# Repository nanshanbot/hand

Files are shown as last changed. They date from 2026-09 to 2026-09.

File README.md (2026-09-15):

# 11 自由度仿生机械手

这是一个基于 STM32F103、PCA9685 和 MediaPipe 的 11 自由度右手机械手项目。项目包含机械结构文件、嵌入式控制固件、串口调试工具，以及普通摄像头手势控制和 RGB-D 连续动作跟随程序。

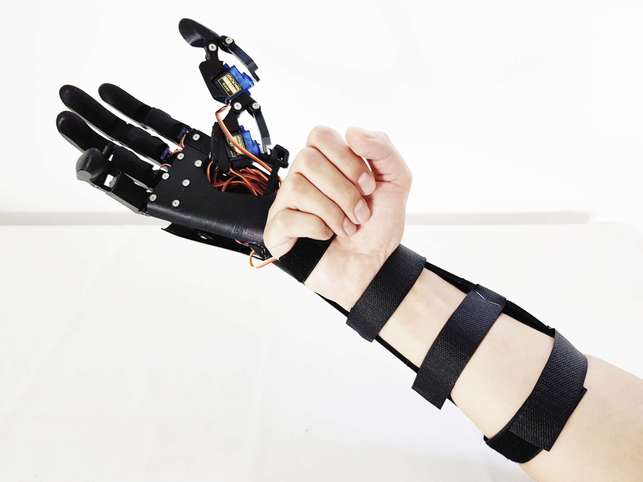
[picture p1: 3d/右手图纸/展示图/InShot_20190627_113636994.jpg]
机械手实物展示


## 功能

- 通过 PCA9685 驱动 11 路舵机
- 通过 USB 转串口独立调试每个关节
- 使用 MediaPipe 识别 8 种常用手势并映射为机械手姿态
- 使用 Orbbec Gemini 336 深度相机估算真实 3D 关节角
- 对识别结果进行稳定帧判断、滤波和舵机速度限制
- 保存和载入 JSON 格式的机械手姿态
- 提供 STL、SolidWorks 源文件、结构图和组装手册

## 项目结构

```text
robot_hand/
├─ 3d/右手图纸/                 # STL、SolidWorks、结构图和组装手册
├─ code/hand/                   # STM32F103 固件
│  ├─ Core/                     # 应用代码与外设初始化
│  ├─ Drivers/                  # STM32 HAL 与 CMSIS
│  └─ tools/hand_debugger/      # Python 串口调试台
└─ code/py/
   ├─ shoushi.py                # 普通摄像头手势识别控制
   ├─ main.py                   # RGB-D 关节角连续跟随
   ├─ gesture_recognizer.task   # MediaPipe 手势识别模型
   └─ hand_landmarker.task      # MediaPipe 手部关键点模型
```

## 硬件

- STM32F103 控制板
- PCA9685 16 路 PWM 驱动板，默认 I2C 地址 `0x40`
- 11 个舵机及机械手结构件
- 3.3 V TTL USB 转串口模块
- 独立舵机电源
- 普通 USB 摄像头，或 Orbbec Gemini 336 RGB-D 相机

> 舵机电源不要直接取自 STM32。舵机电源、STM32 和 PCA9685 必须共地，首次调试建议先卸载拉线或断开舵机负载，确认角度方向和限位正确后再组装。

### USB 转串口接线

| STM32F103 | USB 转串口 |
| --- | --- |
| PA9 / USART1_TX | RX |
| PA10 / USART1_RX | TX |
| GND | GND |

串口参数固定为 `115200, 8N1`。

## 固件编译与烧录

固件工程位于 `code/hand`，由 STM32CubeMX 生成基础工程，并使用 CMake 构建。需要提前安装 ARM GNU Toolchain、CMake 和 Ninja。

```powershell
cd code\hand
cmake --preset Debug
cmake --build --preset Debug
```

生成的固件位于 `code/hand/build/Debug/hand.elf`。可使用 STM32CubeProgrammer、ST-Link 或支持 ELF 文件的调试器烧录。修改 CubeMX 配置时请使用 `code/hand/hand.ioc`。

## 串口调试台

Windows 下可直接双击：

```text
code\hand\tools\hand_debugger\run.cmd
```

也可以在 PowerShell 中运行：

```powershell
cd code\hand
.\tools\hand_debugger\run.ps1
```

脚本首次启动会在工具目录创建虚拟环境并安装 `pyserial`。连接串口后，可以分别调整 11 路关节角、实时下发命令、预览姿态，以及保存或载入姿态文件。

通道定义如下：

| 通道 | 关节 | 角度范围 |
| --- | --- | --- |
| CH0 | 拇指旋转 | 5-140° |
| CH1 | 拇指近端 | 5-170° |
| CH2 | 拇指远端 | 5-140° |
| CH3-CH4 | 食指近端、远端 | 5-170° |
| CH5-CH6 | 中指近端、远端 | 5-170° |
| CH7-CH8 | 无名指近端、远端 | 5-170° |
| CH9-CH10 | 小指近端、远端 | 5-170° |

## 视觉控制

建议使用 Python 3.10 创建独立环境：

```powershell
cd code\py
py -3.10 -m venv .venv
.\.venv\Scripts\Activate.ps1
python -m pip install -r requirements.txt
```

RGB-D 模式还需要按 [Orbbec SDK 文档](https://github.com/orbbec/pyorbbecsdk) 安装与设备、系统匹配的 `pyorbbecsdk`。

### 普通摄像头手势控制

`shoushi.py` 使用 MediaPipe 内置手势分类器，将 `Closed_Fist`、`Open_Palm`、`Victory` 等手势映射为预设的 11 路舵机角度。

```powershell
python shoushi.py --port COM20 --camera 0
```

使用其他串口或摄像头时修改对应参数。运行中按空格键暂停或恢复控制，按 `Q` 退出。执行下面的命令可以进入姿态标定模式：

```powershell
python shoushi.py --calibrate --camera 0
```

### RGB-D 连续动作跟随

`main.py` 面向 Orbbec Gemini 336。程序使用彩色图像检测 21 个手部关键点，再利用对齐的深度图反投影到相机坐标系，经过骨长约束和平滑处理后映射到舵机角度。

```powershell
python main.py --port COM20 --debug
```

关节范围标定：

```powershell
python main.py --calibrate
```

标定窗口中，右手完全伸直时按 `1`，完全握拳时按 `2`，各采集多组数据后按 `3` 输出新的 `MP_RANGES`。

> 当前仓库缺少 `code/py/rgbd_hand_3d.py` 源文件，`main.py` 在补回该模块前无法从全新环境运行。该模块应提供 Gemini 336 采集、深度反投影、骨长约束和关键点平滑功能；请不要用 `__pycache__` 中的 `.pyc` 文件代替源码上传。

## 串口协议

每条 ASCII 命令以回车或换行结束：

```text
PING          -> PONG
GET           -> STATE 5,5,5,5,5,5,5,5,5,5,5
SET 0 90      -> OK
ALL 5         -> OK
```

- `SET <通道> <角度>` 设置单路舵机。
- `ALL <角度>` 设置全部舵机；CH0 和 CH2 最高会限制在 140°。
- 参数或通信异常时，控制板返回以 `ERR` 开头的错误信息。

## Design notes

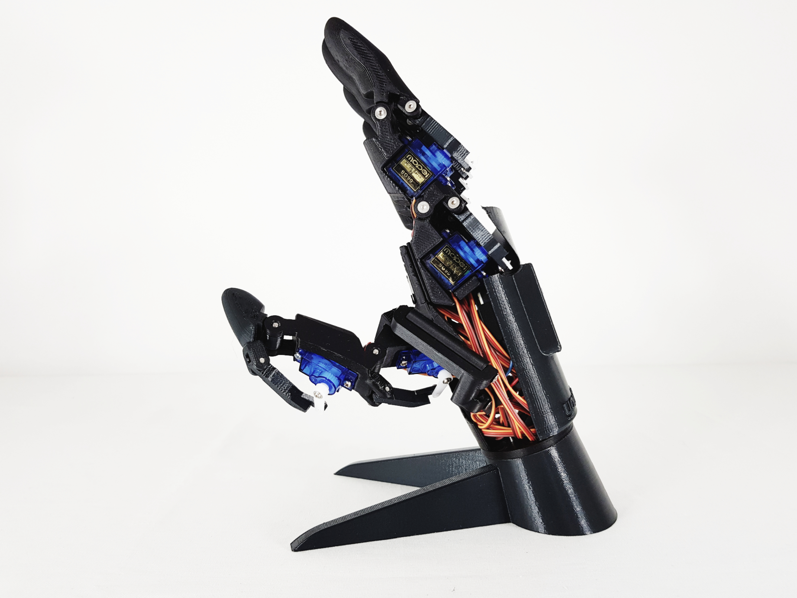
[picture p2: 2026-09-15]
3d/右手图纸/展示图/InShot_20190323_112702161.jpg

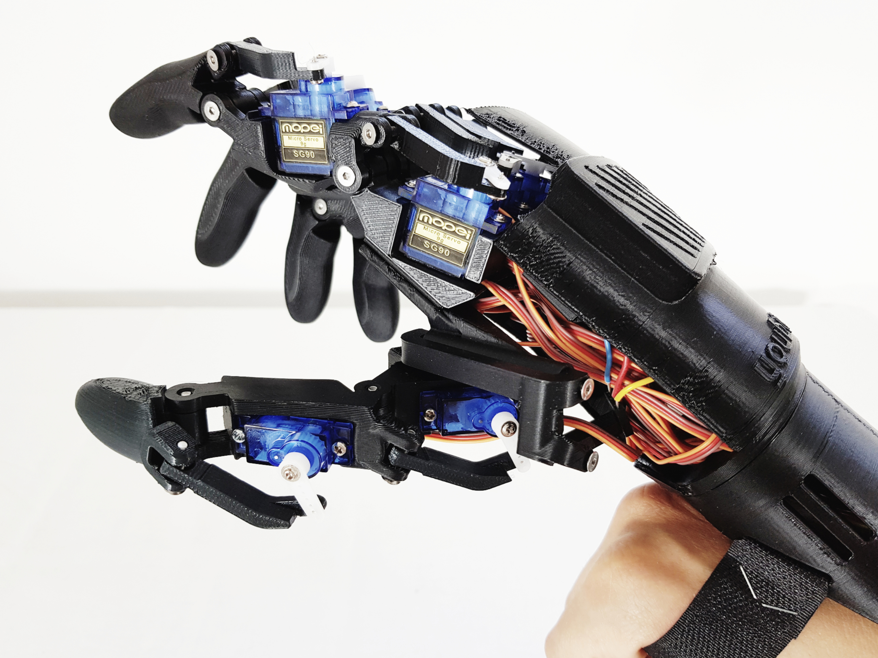
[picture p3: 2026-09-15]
3d/右手图纸/展示图/InShot_20190627_113036899.jpg

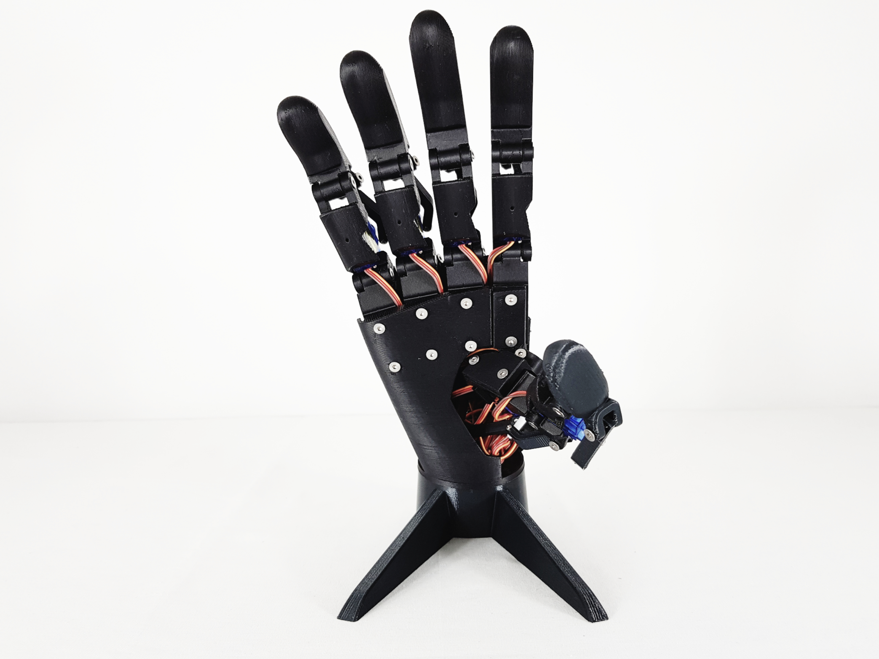
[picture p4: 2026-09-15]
3d/右手图纸/展示图/InShot_20190323_112803288.jpg

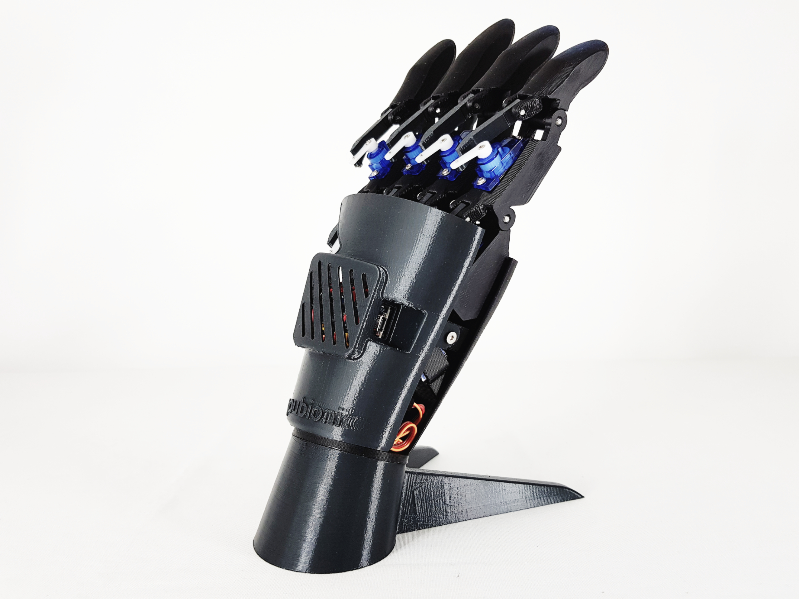
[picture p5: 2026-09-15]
3d/右手图纸/展示图/InShot_20190323_112944940.jpg

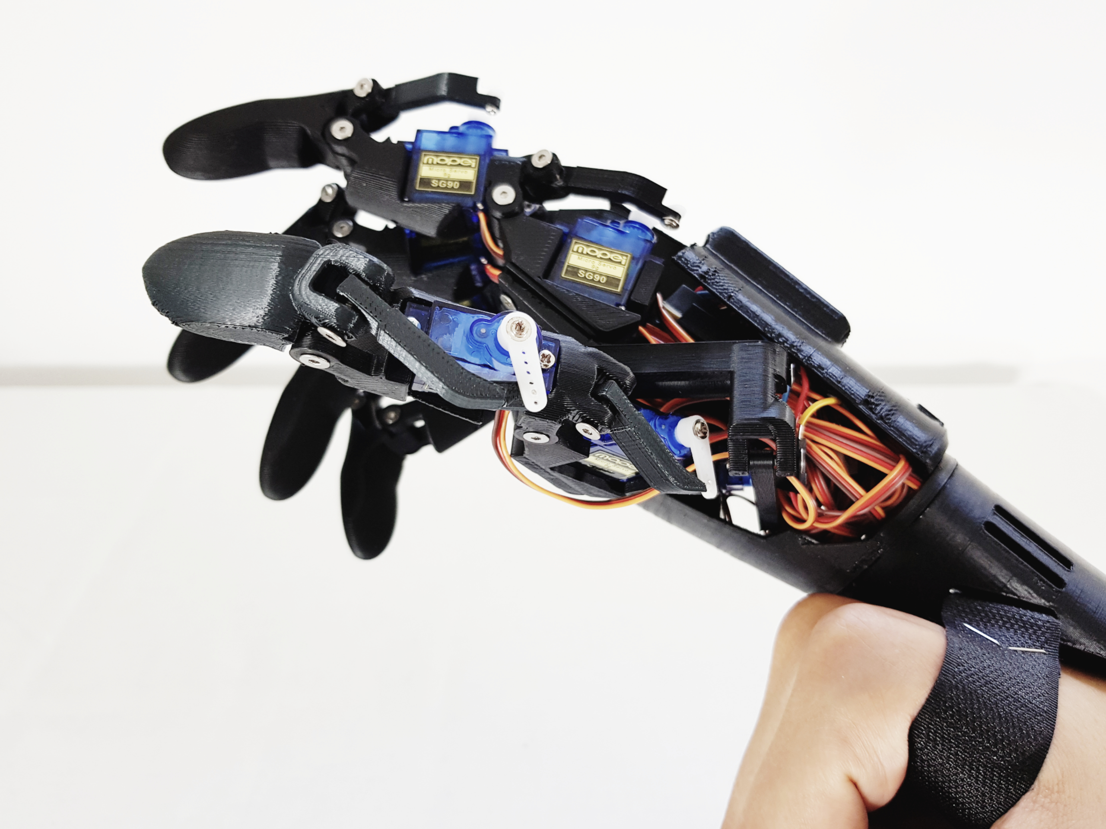
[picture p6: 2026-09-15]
3d/右手图纸/展示图/InShot_20190627_113151180.jpg

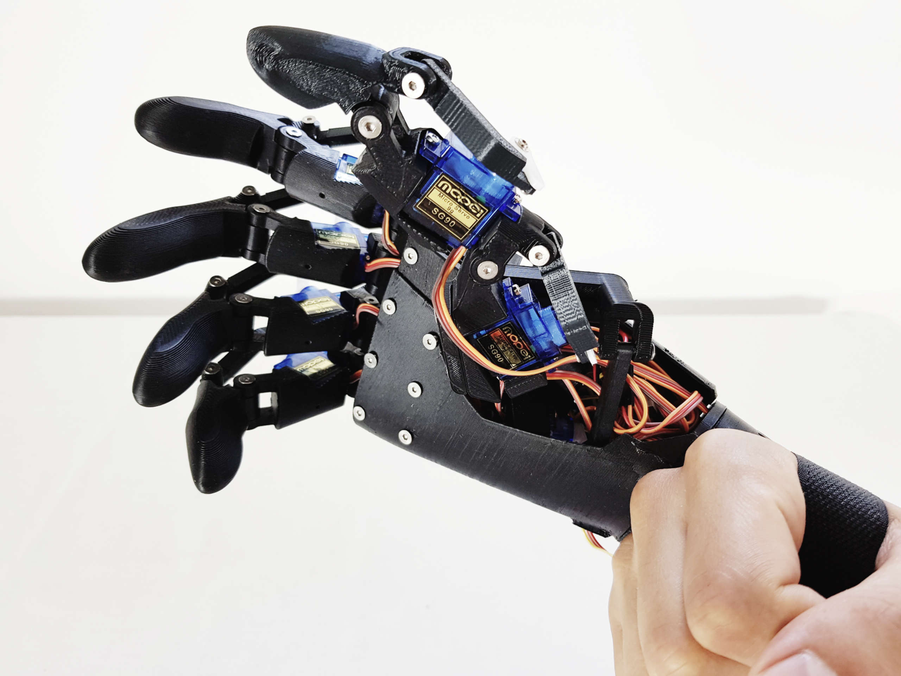
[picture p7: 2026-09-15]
3d/右手图纸/展示图/InShot_20190627_113228893.jpg

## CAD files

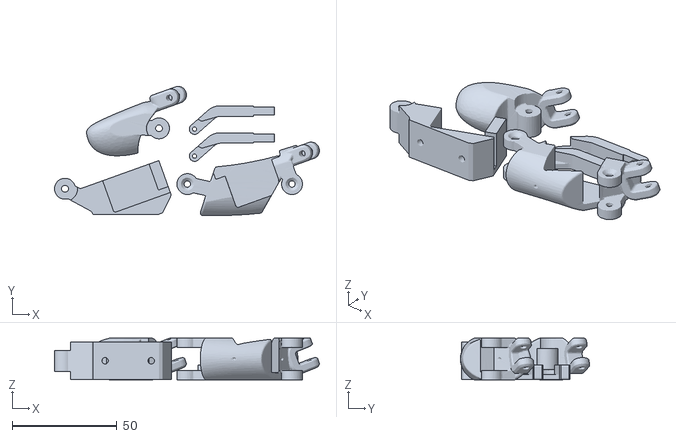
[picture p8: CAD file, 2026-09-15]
3d/右手图纸/stl/Handy_Thumb.stl
126.6 x 61.8 x 20.0

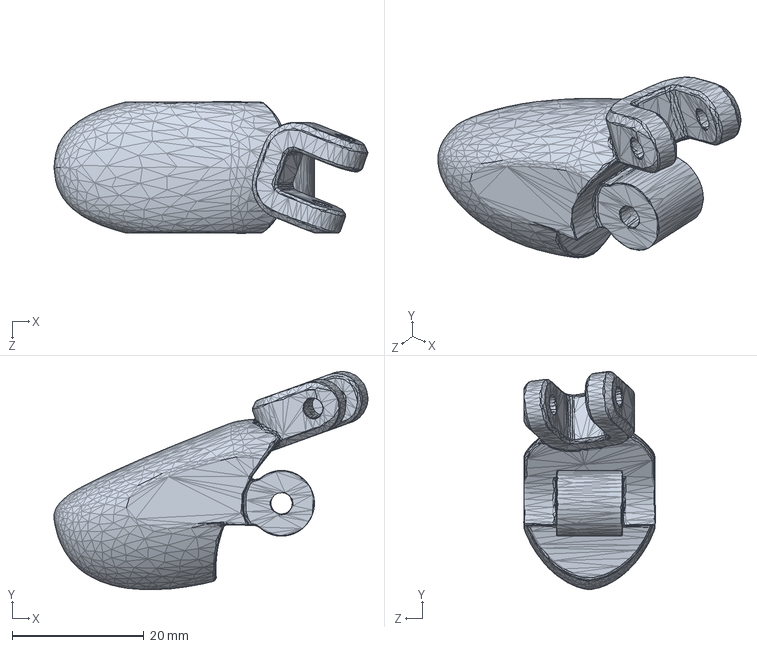
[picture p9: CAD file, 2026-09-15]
3d/右手图纸/sw/Handy_Thumb.SLDPRT
47.8 x 33.2 x 20.0 mm

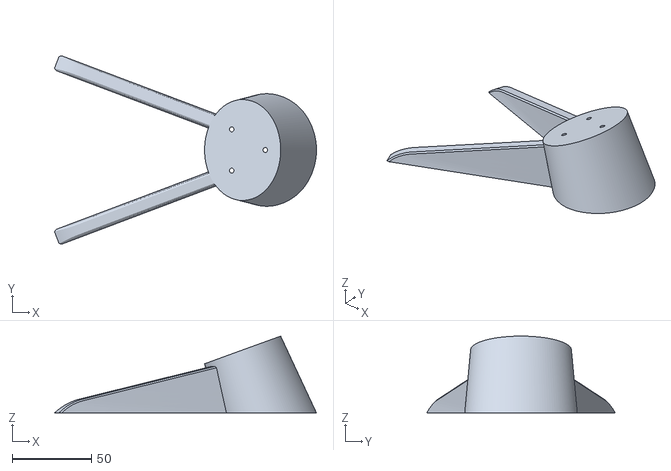
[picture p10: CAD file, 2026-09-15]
3d/右手图纸/stl/Handy_Dock Station.stl
165.0 x 118.6 x 48.4

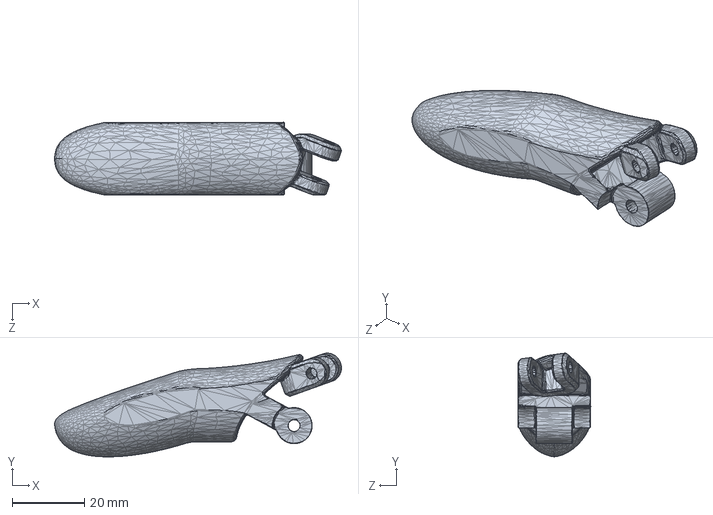
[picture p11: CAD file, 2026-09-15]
3d/右手图纸/sw/Handy_Middle.SLDPRT
79.4 x 28.7 x 20.2 mm

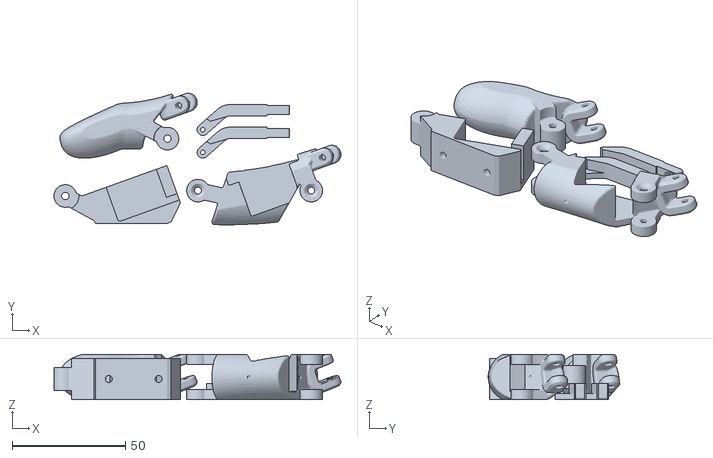
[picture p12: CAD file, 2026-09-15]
3d/右手图纸/stl/Handy_Pinkie.stl
126.7 x 58.1 x 20.0

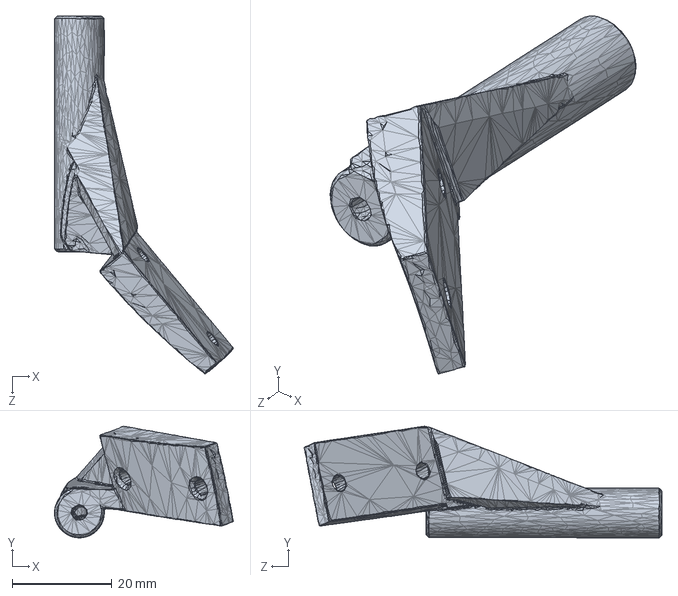
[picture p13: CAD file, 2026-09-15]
3d/右手图纸/sw/Handy_Palm and Rotation - Right update2.SLDPRT
35.9 x 22.4 x 71.8 mm

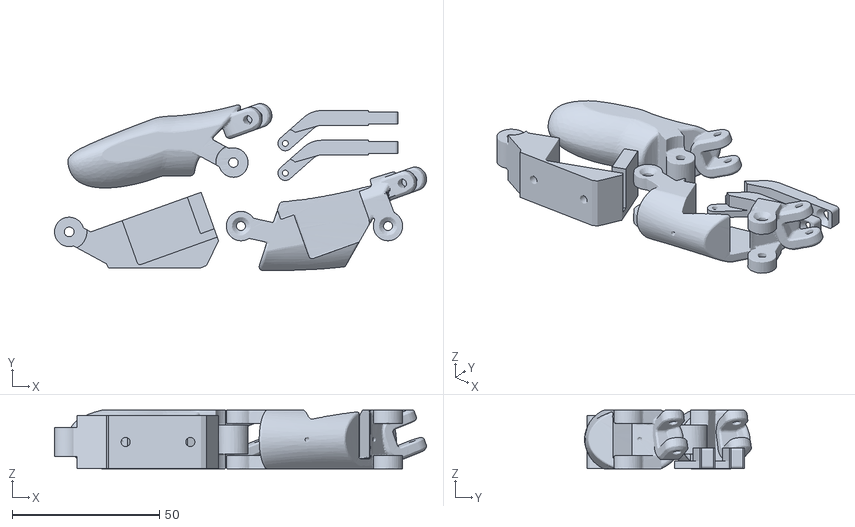
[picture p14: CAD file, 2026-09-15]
3d/右手图纸/stl/Handy_Index.stl
126.5 x 56.7 x 20.0

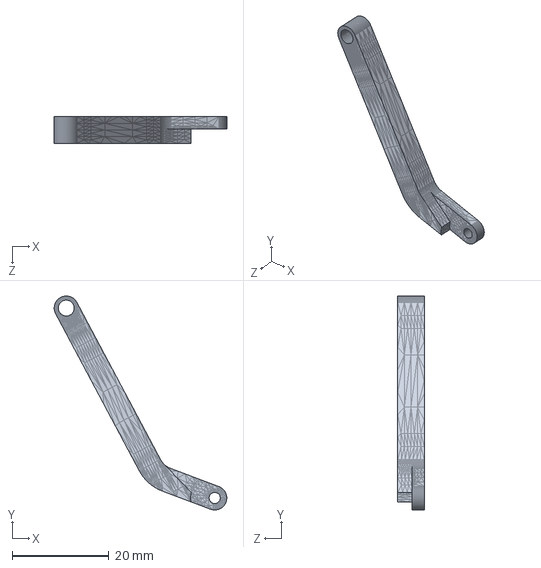
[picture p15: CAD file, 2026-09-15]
3d/右手图纸/sw/Handy_Palm and Rotation - Right update3.SLDPRT
35.8 x 44.3 x 5.50 mm

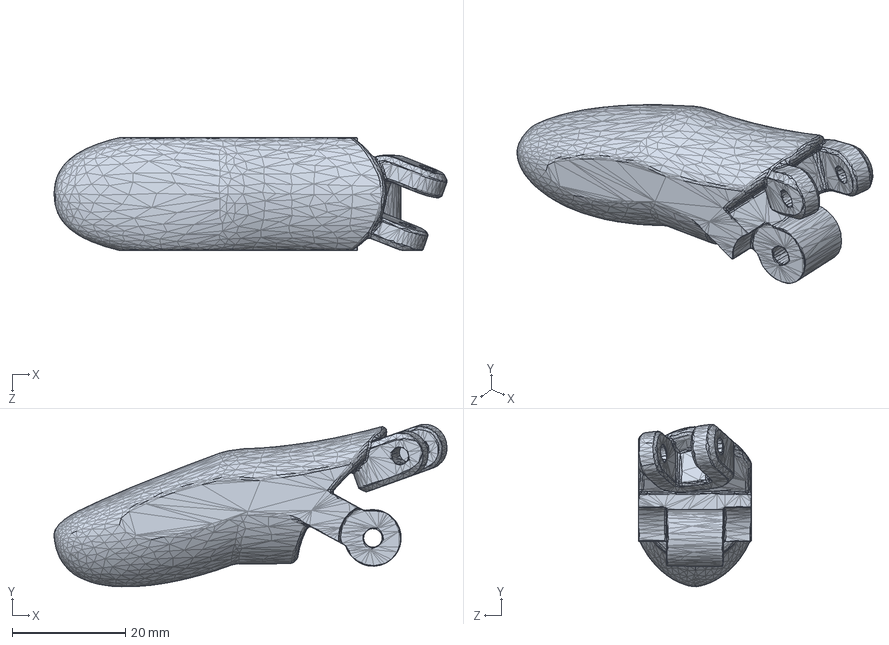
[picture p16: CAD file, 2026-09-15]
3d/右手图纸/sw/Handy_Index.SLDPRT
69.4 x 28.7 x 20.0 mm

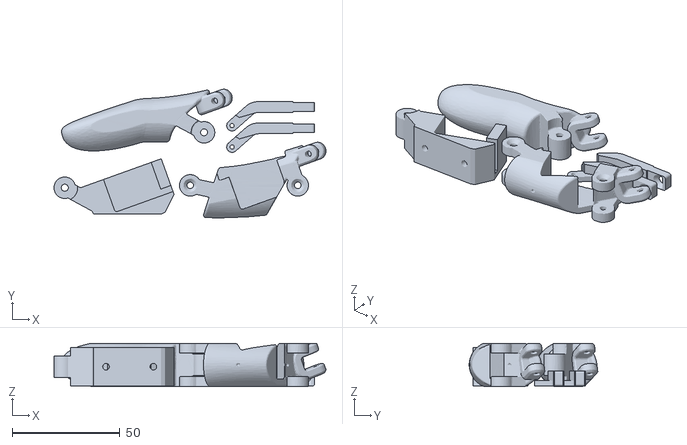
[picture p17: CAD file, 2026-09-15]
3d/右手图纸/stl/Handy_Middle.stl
126.4 x 59.8 x 20.2

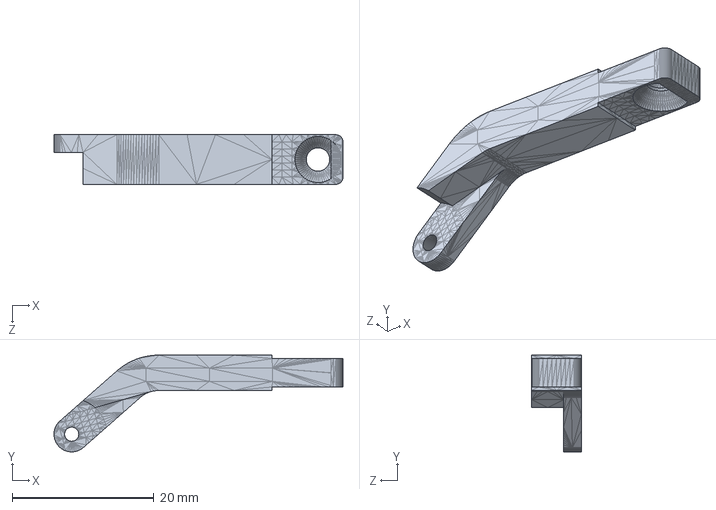
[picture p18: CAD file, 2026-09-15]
3d/右手图纸/sw/Handy_Middle3.SLDPRT
40.8 x 13.7 x 7.00 mm

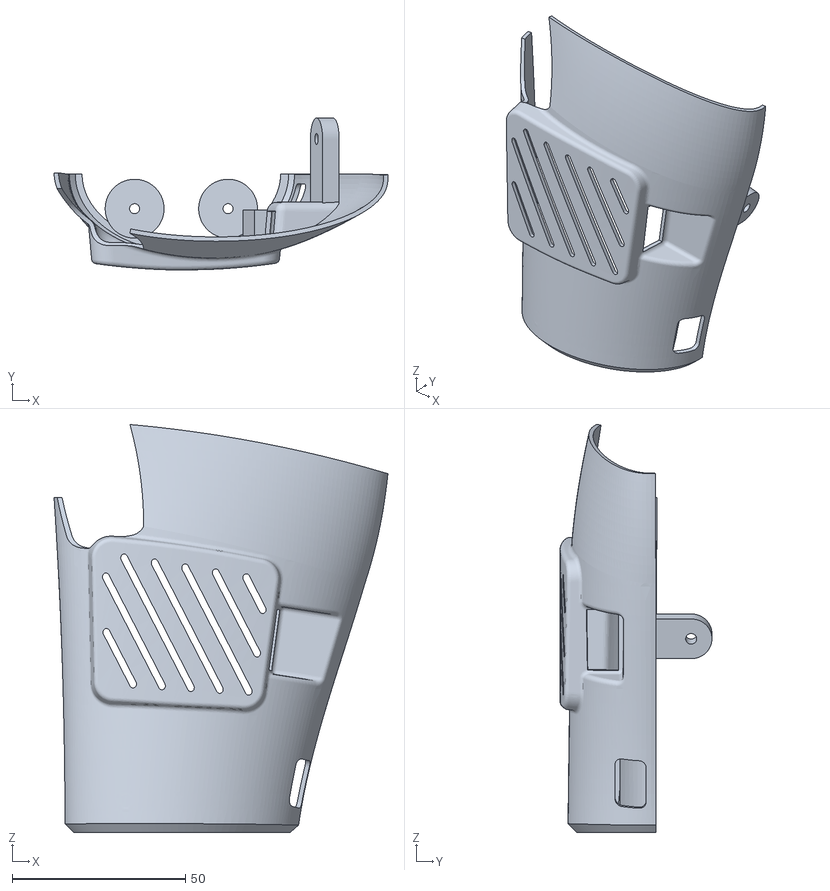
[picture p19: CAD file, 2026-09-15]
3d/右手图纸/stl/Handy_Back - Right-抹字.stl
96.5 x 43.9 x 117.9

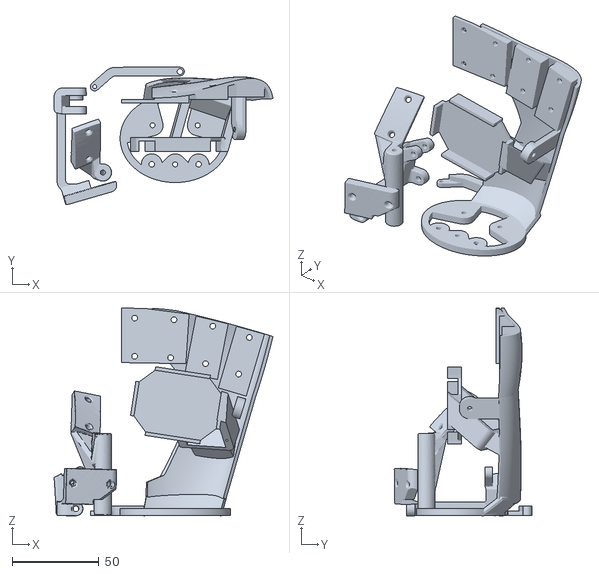
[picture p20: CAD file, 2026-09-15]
3d/右手图纸/stl/Handy_Palm and Rotation - Right update.stl
126.2 x 79.3 x 119.9

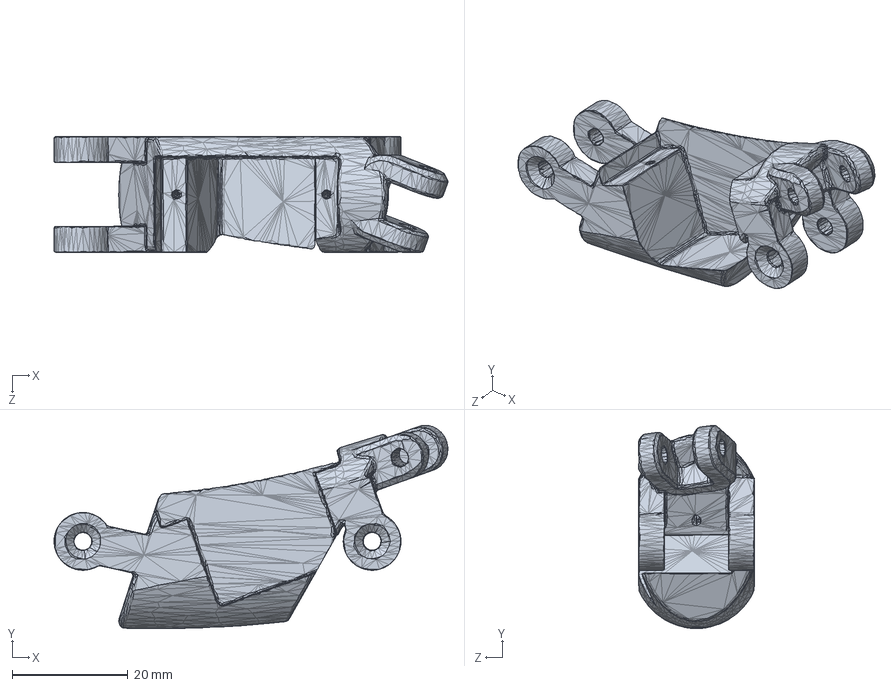
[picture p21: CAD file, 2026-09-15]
3d/右手图纸/sw/Handy_Middle2.SLDPRT
68.1 x 35.2 x 20.0 mm

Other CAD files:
3d/右手图纸/sw/Handy_Index1.SLDPRT
3d/右手图纸/sw/Handy_Middle1.SLDPRT
3d/右手图纸/sw/Handy_Pinkie.SLDPRT
3d/右手图纸/sw/Handy_Dock Station.SLDPRT
3d/右手图纸/sw/Handy_Palm and Rotation - Right update1.SLDPRT
3d/右手图纸/sw/Handy_Ring.SLDPRT

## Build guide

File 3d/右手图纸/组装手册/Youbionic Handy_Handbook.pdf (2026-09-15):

# YOUBIONIC HANDY

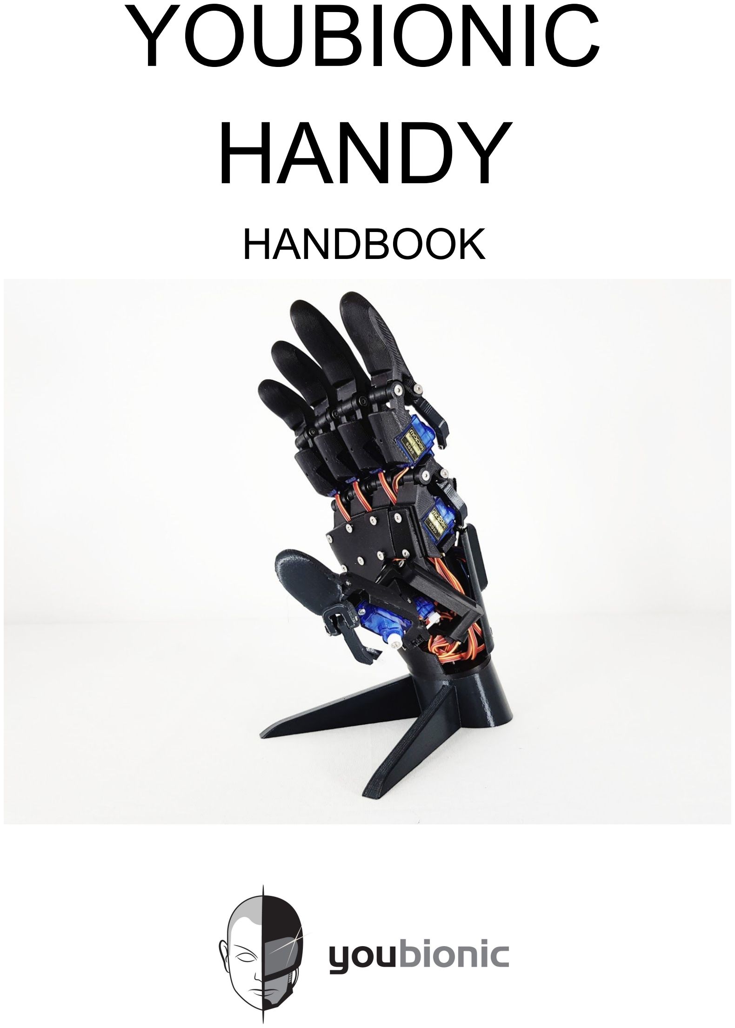
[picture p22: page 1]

# HANDBOOK

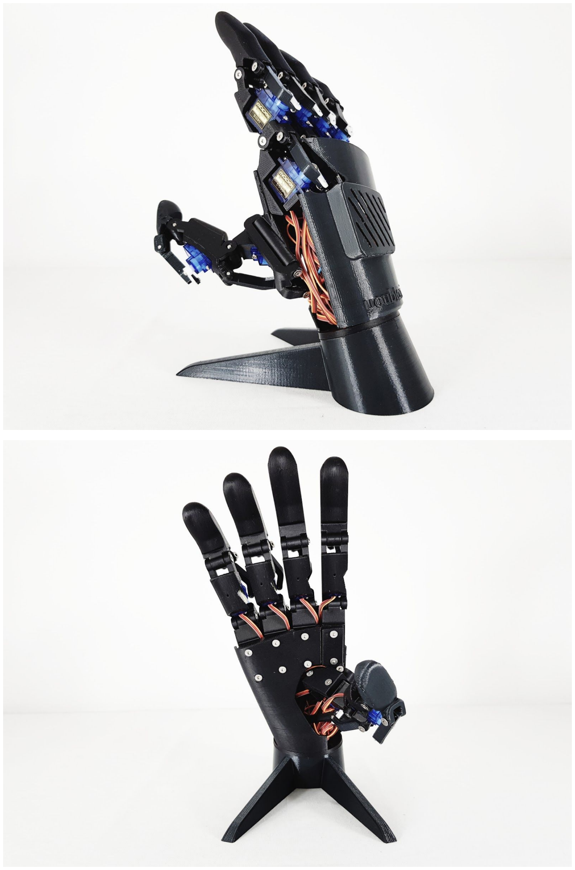
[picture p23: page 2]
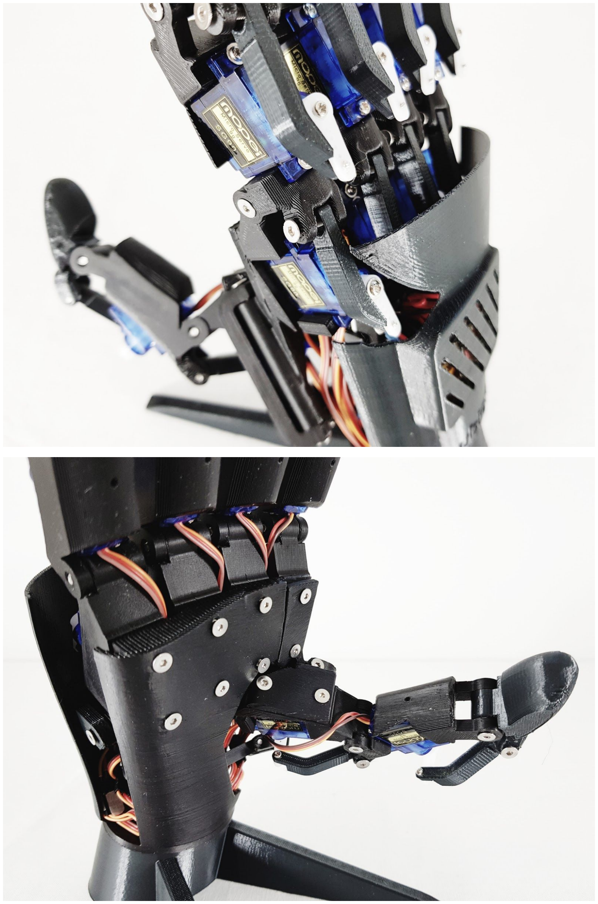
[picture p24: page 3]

# ASSEMBLY INSTRUCTIONS

N°1 Handy 3d printing Parts

N°11 Servo Motor SG90

N°1 Arduino Nano

N°1 Breadboard 170 Points

N°1 Jumper wires pack

During the Assembly don’t screw the screws all the way down, let the pieces rotate (make sure that the pieces can rotate, but leave a slight friction).

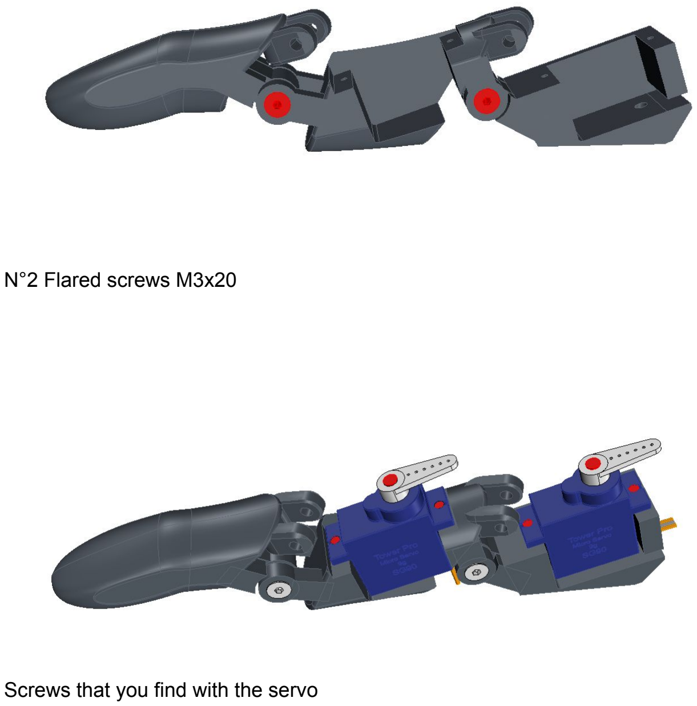
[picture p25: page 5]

N°2 Flared screws M3x20

Screws that you find with the servo

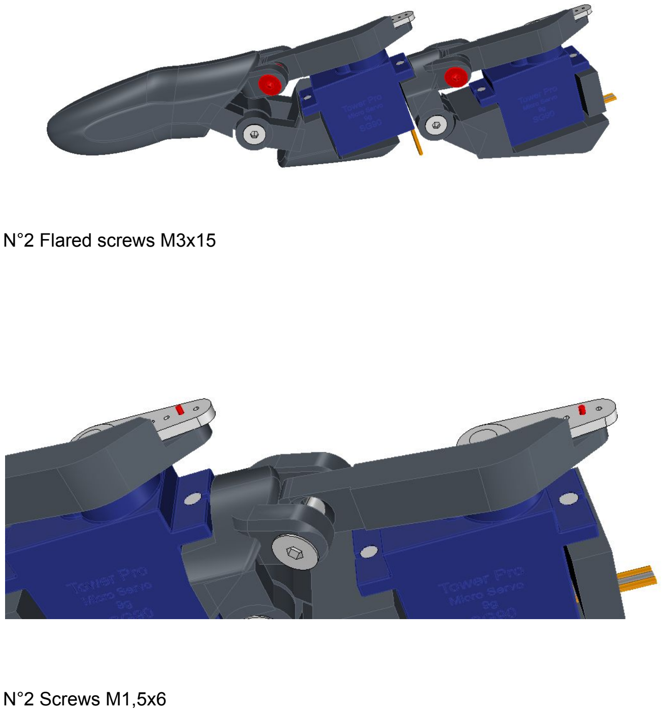
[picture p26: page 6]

N°2 Flared screws M3x15

N°2 Screws M1,5x6

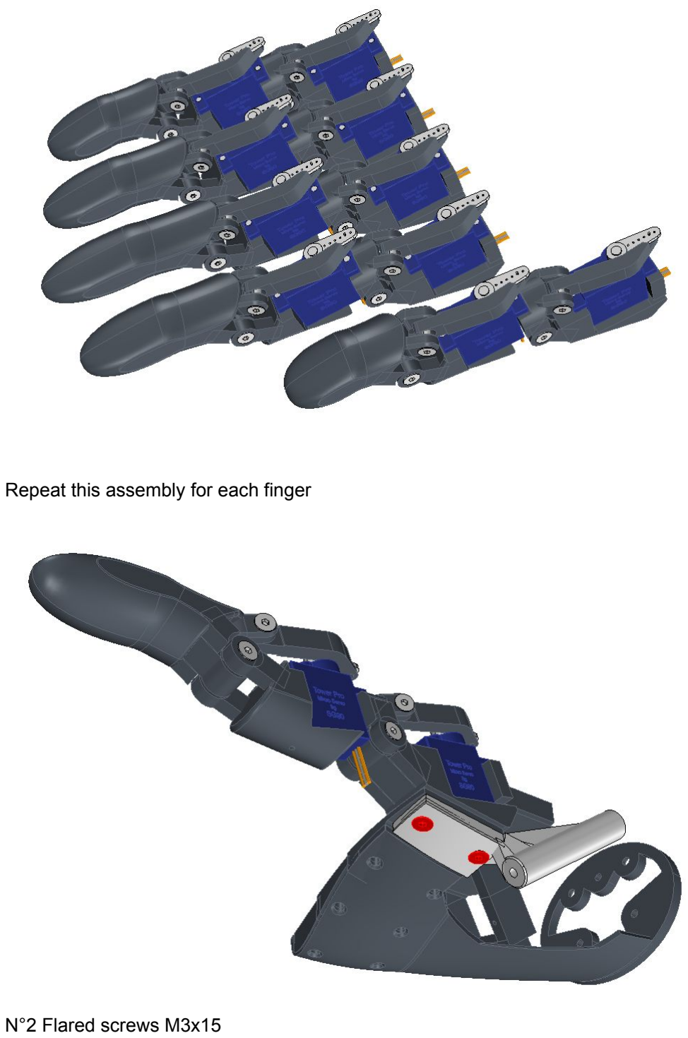
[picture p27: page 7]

Repeat this assembly for each finger

N°2 Flared screws M3x15

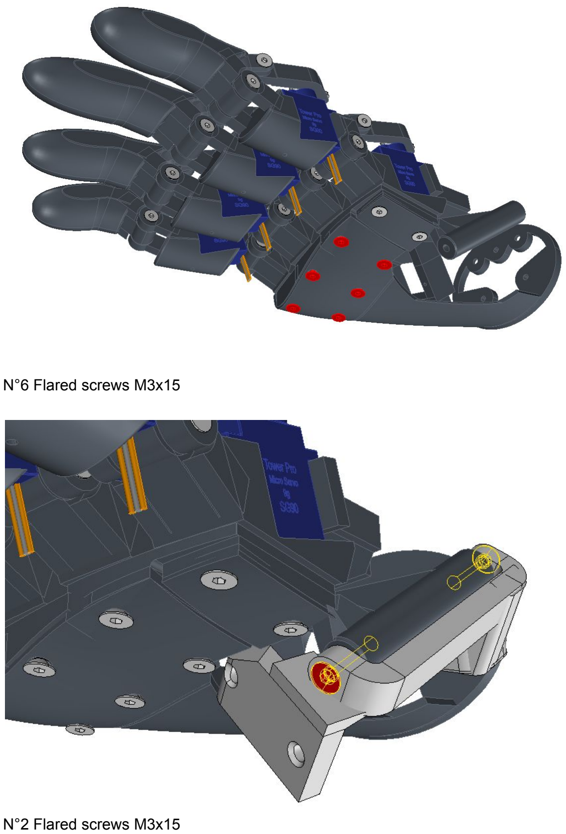
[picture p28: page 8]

N°6 Flared screws M3x15

N°2 Flared screws M3x15

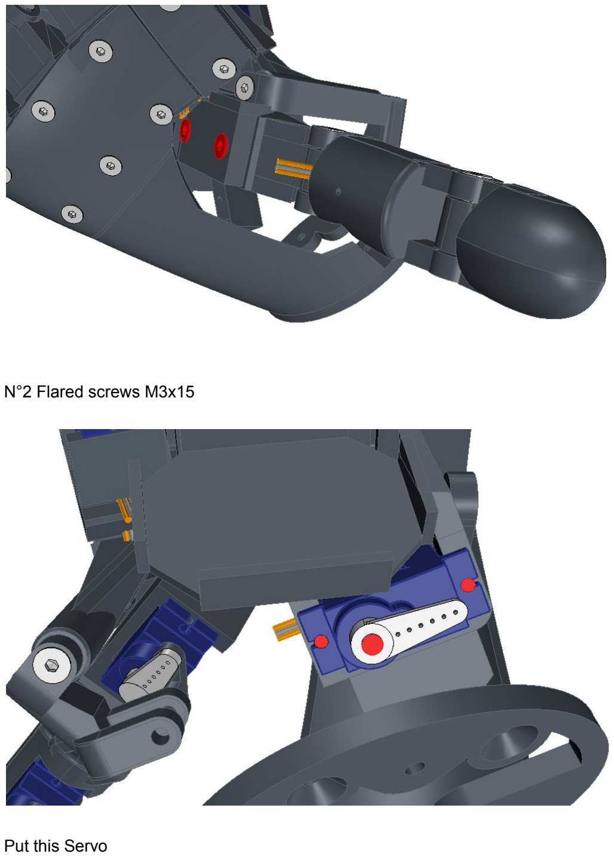
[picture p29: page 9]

N°2 Flared screws M3x15

Put this Servo

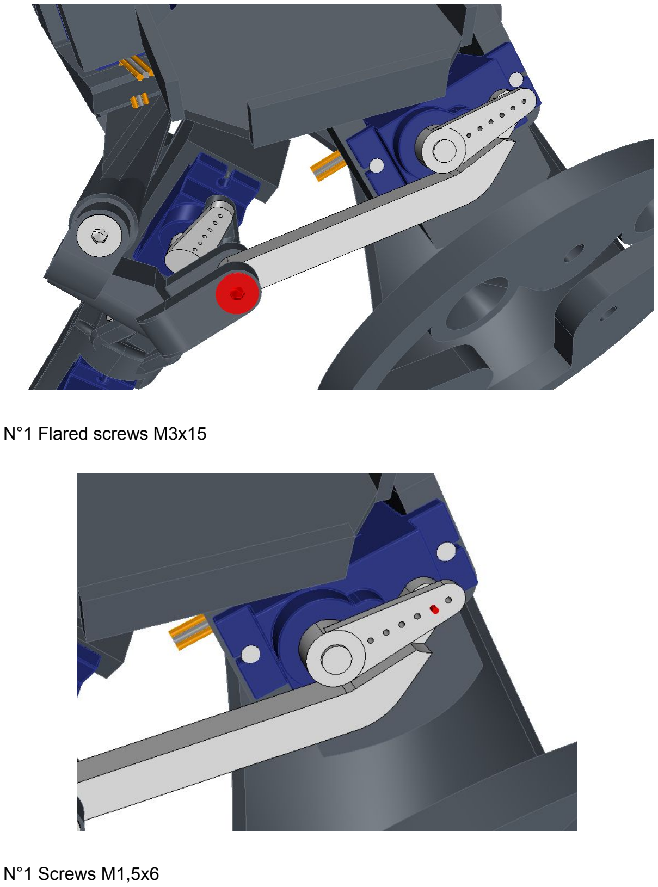
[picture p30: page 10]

N°1 Flared screws M3x15

N°1 Screws M1,5x6

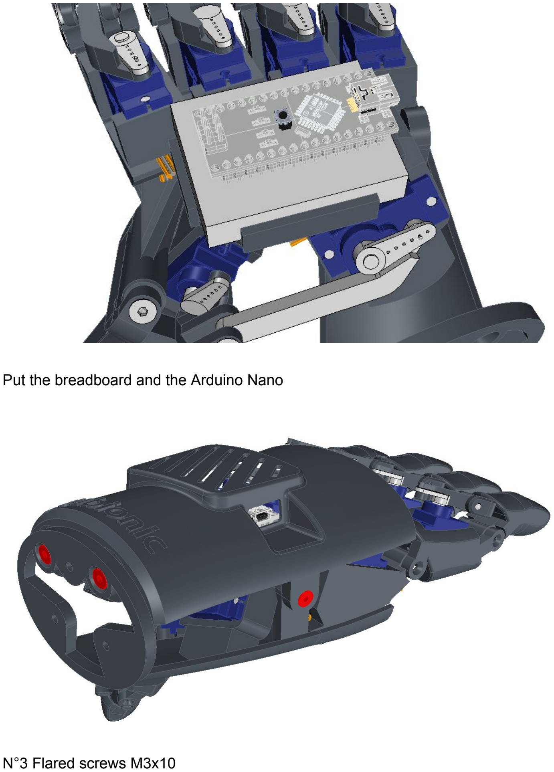
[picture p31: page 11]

Put the breadboard and the Arduino Nano

N°3 Flared screws M3x10

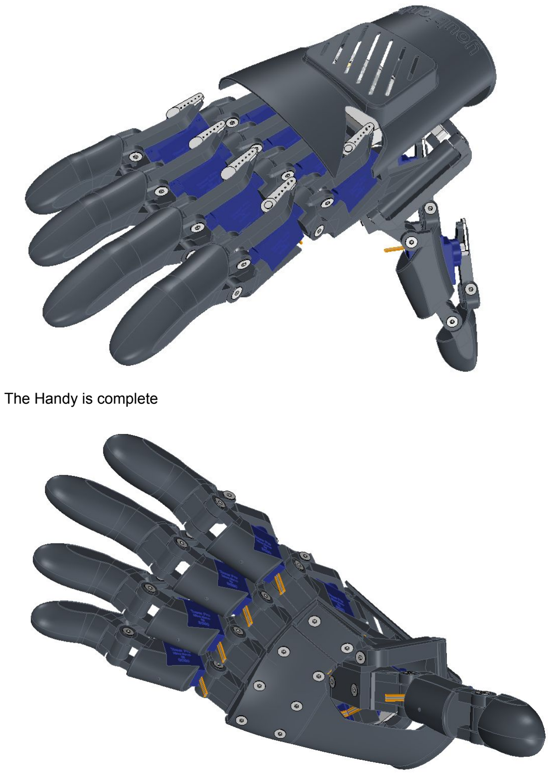
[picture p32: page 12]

The Handy is complete

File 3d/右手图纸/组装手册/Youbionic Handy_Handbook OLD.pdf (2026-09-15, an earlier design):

# YOUBIONIC HANDY

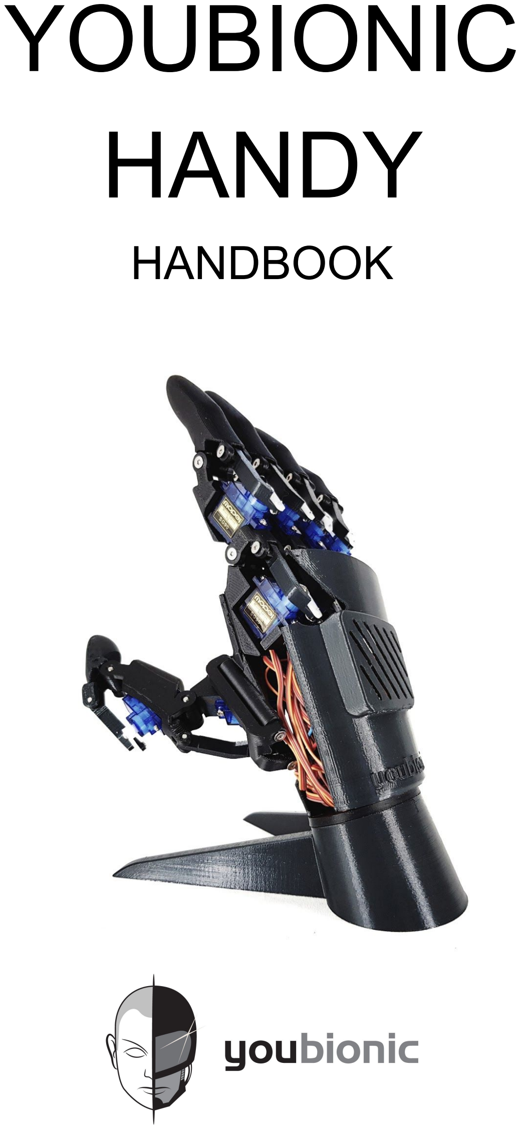
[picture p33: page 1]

# HANDBOOK

### We have worked to obtain the best technology in the simplest mechanics, both for printing and assembly

# INDEX

Bill of material

Assembly instructions

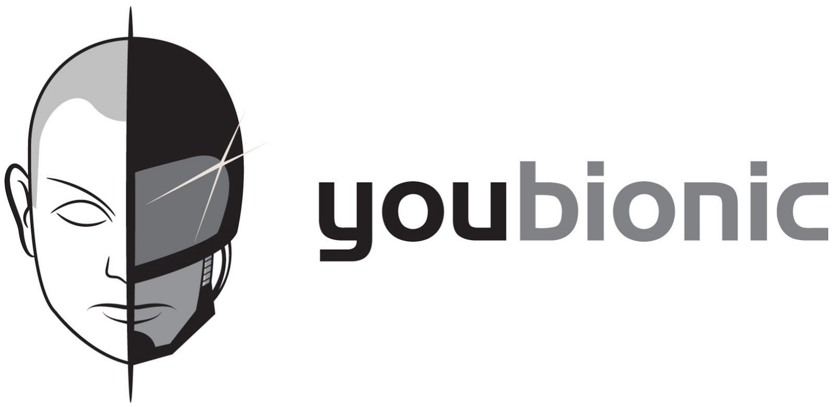
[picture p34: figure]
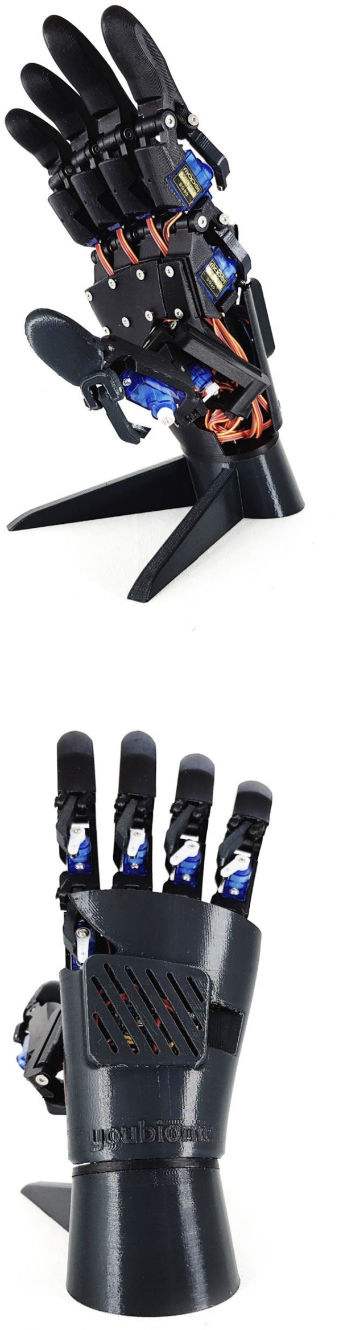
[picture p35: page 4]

# BILL OF MATERIAL

N°1 3D Handy prints
- Fingers
- Palm
- Rotation system
- Back
- Dock station (if you want)

N°11 Servo Motor SG90
- to buy: https://www.aliexpress.com/w/wholesale-sg90-servo.html

N°10 Flared screws M3x20 for finger assembly
- to buy

N°10 Flared screws M3x15 for finger servo bracket
- to buy

N°10 Flared screws M3x15 to assemble the fingers to the Palm
- to buy

N°3 Flared screws M3x15 to assemble the Rotation Thumb System
- to buy

N°3 Flared screws M3x10 to assemble the Back part
- to buy

N°3 Flared screws M3x10 to assemble the Dock support
- to buy

# ASSEMBLY INSTRUCTIONS

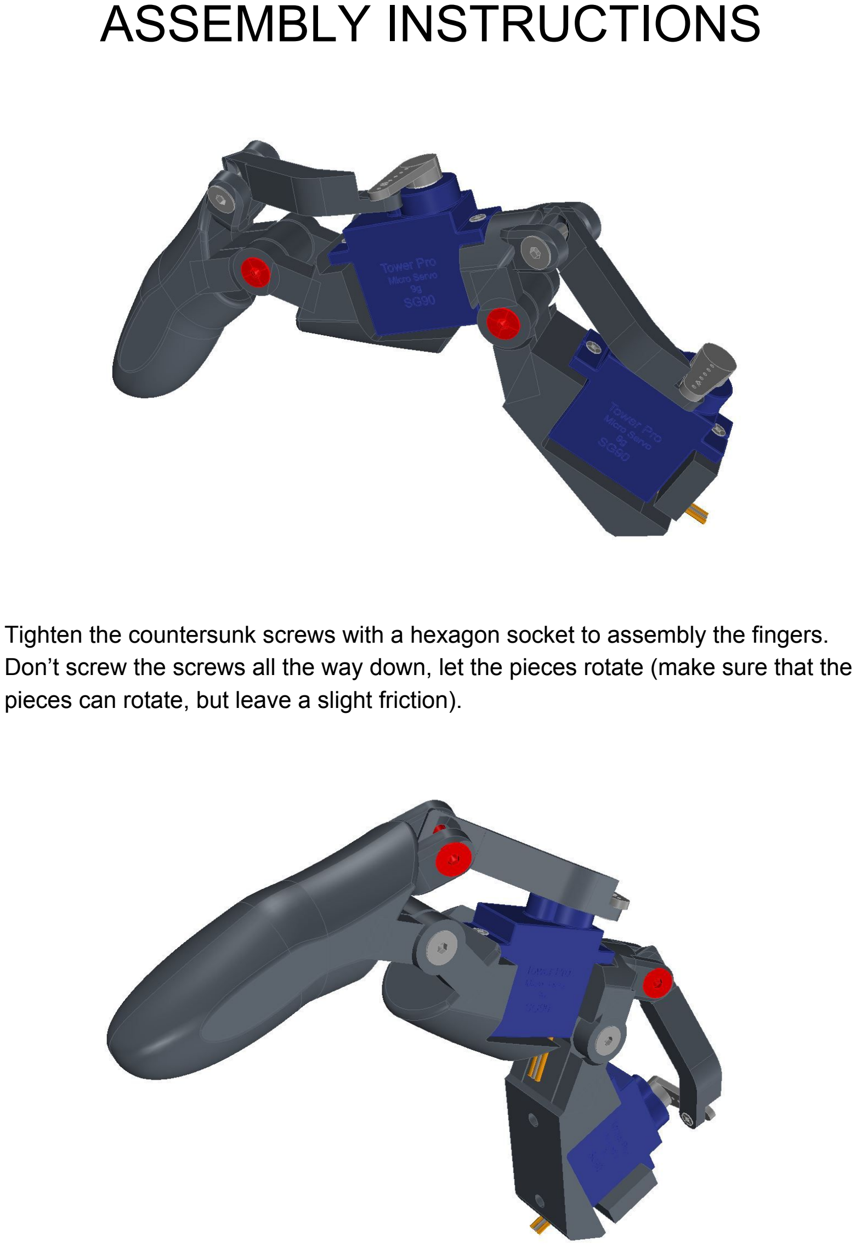
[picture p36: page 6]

Tighten the countersunk screws with a hexagon socket to assembly the fingers. Don’t screw the screws all the way down, let the pieces rotate (make sure that the pieces can rotate, but leave a slight friction).

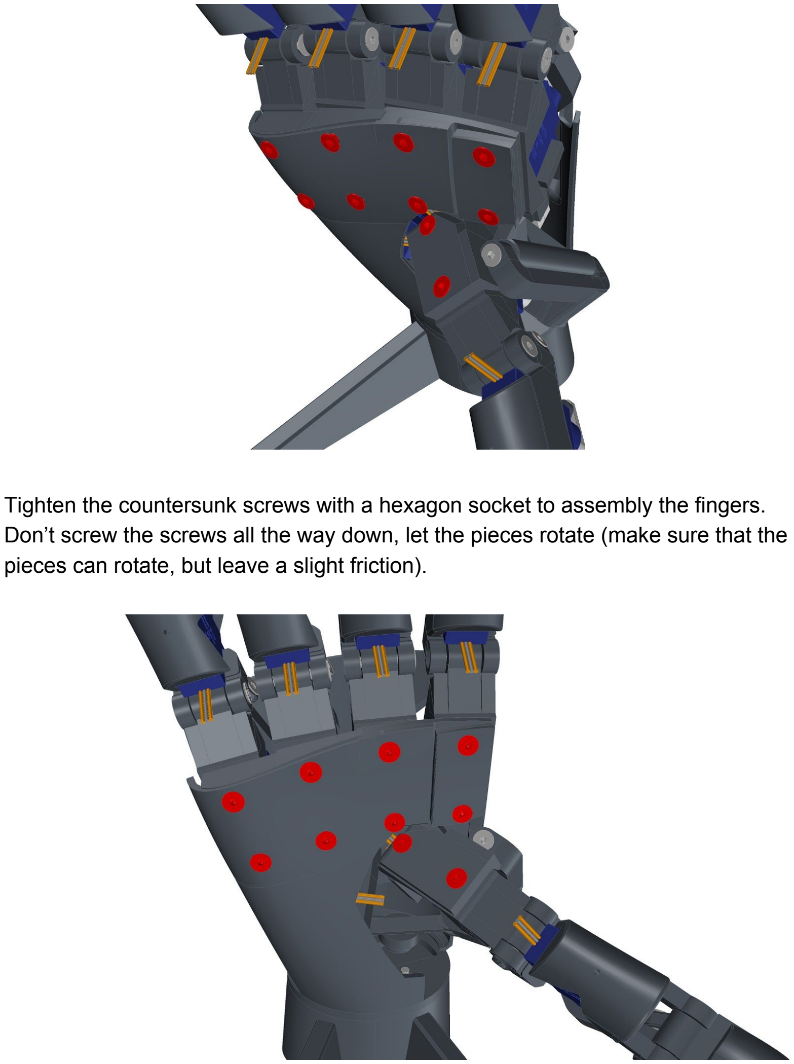
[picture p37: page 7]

Tighten the countersunk screws with a hexagon socket to assembly the fingers. Don’t screw the screws all the way down, let the pieces rotate (make sure that the pieces can rotate, but leave a slight friction).

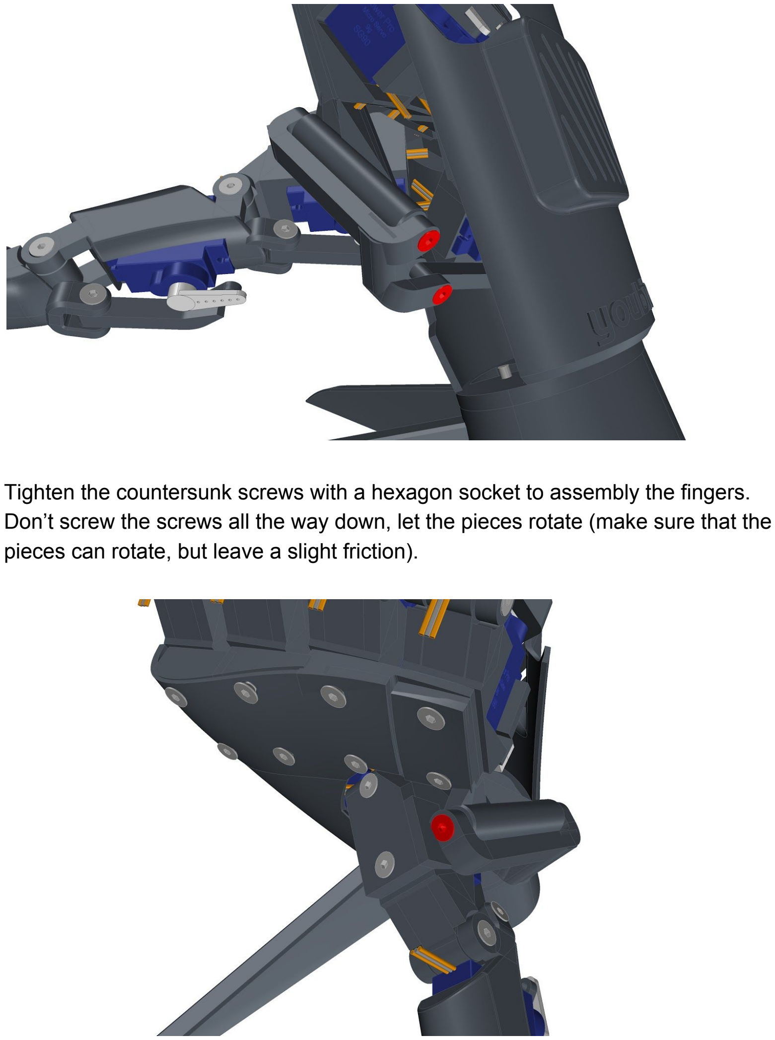
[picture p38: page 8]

Tighten the countersunk screws with a hexagon socket to assembly the fingers. Don’t screw the screws all the way down, let the pieces rotate (make sure that the pieces can rotate, but leave a slight friction).

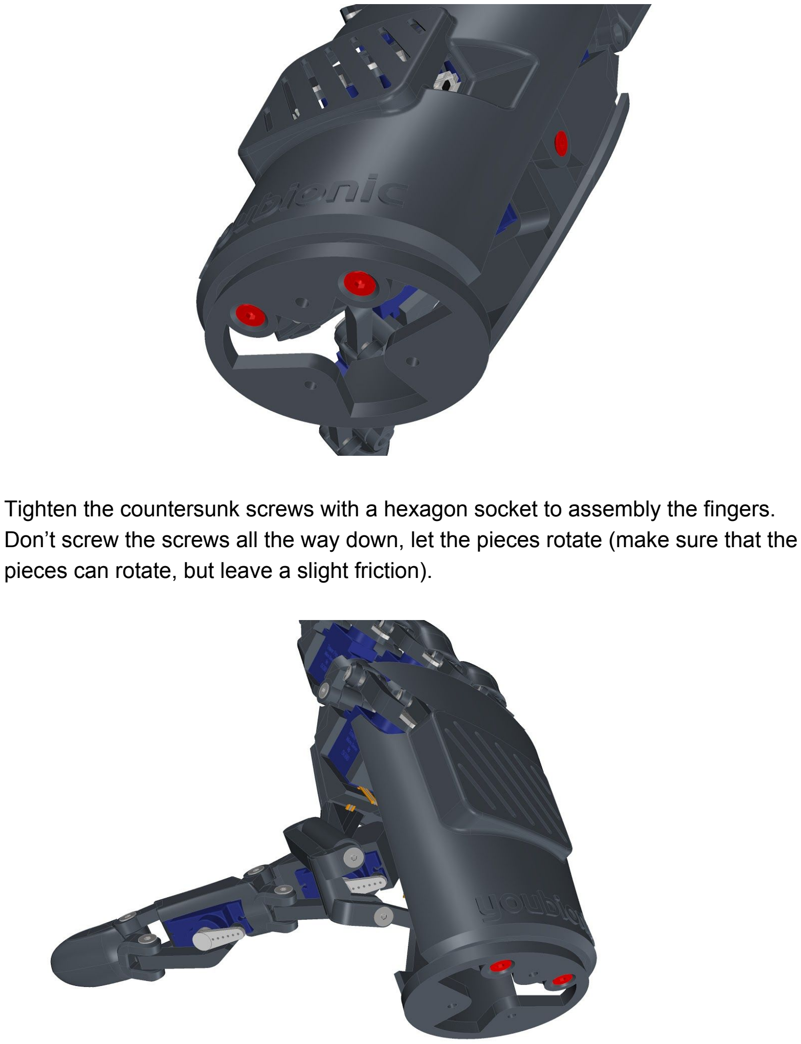
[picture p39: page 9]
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

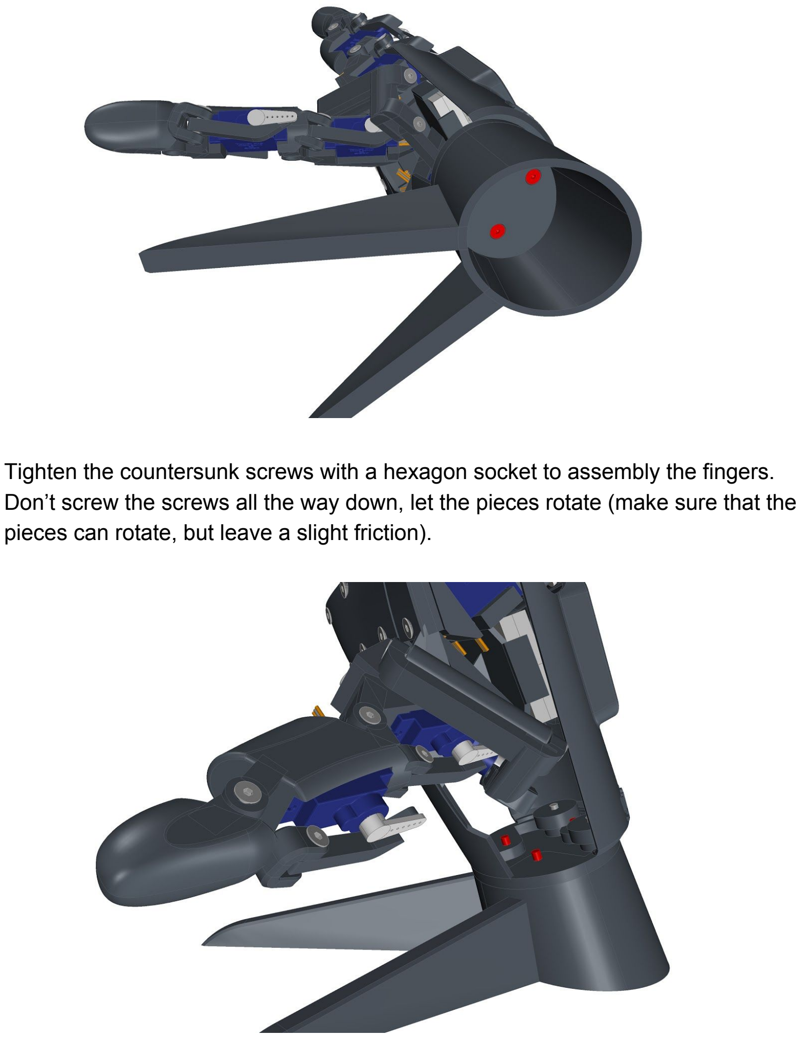
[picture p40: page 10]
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

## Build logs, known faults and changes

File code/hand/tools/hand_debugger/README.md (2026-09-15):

# 11 自由度灵巧手调试台

## 启动

直接双击 `run.cmd`，或在 PowerShell 中执行：

```powershell
.\tools\hand_debugger\run.ps1
```

首次启动会在工具目录创建独立 Python 虚拟环境并安装 `pyserial`。选择串口后点击“连接”即可。串口参数固定为 `115200, 8N1`。

## 接线

| STM32F103 | USB 转串口 |
| --- | --- |
| PA9 / USART1_TX | RX |
| PA10 / USART1_RX | TX |
| GND | GND |

USB 转串口应使用 3.3V TTL 电平。舵机应使用独立电源，并与 STM32、PCA9685 共地。

## 默认通道

CH0–CH2 为拇指三个自由度；CH3–CH10 依次为食指、中指、无名指、小指的近端和远端自由度。若实际机械接线不同，只需修改 `app.py` 中的 `SERVO_NAMES` 顺序，固件通道号不变。

## 串口协议

每条命令以回车或换行结束。CH0（拇指旋转）和 CH2（拇指远端）的角度范围为 5–140°，其余通道为 5–170°。`ALL` 命令超过 140° 时，CH0 和 CH2 会停在 140°，其余通道使用命令指定的角度。

```text
PING          -> PONG
GET           -> STATE 5,5,5,5,5,5,5,5,5,5,5
SET 0 90      -> OK
ALL 5         -> OK
```

无效参数会返回 `ERR ...`。上电时仅初始化 CH0–CH10 为 5°，不会驱动其余 PCA9685 通道。

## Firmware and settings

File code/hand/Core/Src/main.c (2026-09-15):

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
/* Includes ------------------------------------------------------------------*/
#include "main.h"
#include "i2c.h"
#include "gpio.h"

/* USER CODE BEGIN Includes */
#include "pca9685.h"
#include "serial_port.h"
#include <stdlib.h>
#include <string.h>

/* USER CODE END Includes */

/* USER CODE BEGIN PD */
#define HAND_SERVO_COUNT  11U
#define HAND_ANGLE_MIN    5U
#define HAND_ANGLE_MAX    170U
#define HAND_THUMB_ANGLE_MAX  140U
#define HAND_THUMB_ROTATION_CHANNEL  0U
#define HAND_THUMB_DISTAL_CHANNEL    2U
#define RX_LINE_SIZE      48U

/* USER CODE END PD */


/* USER CODE BEGIN PV */
static uint8_t servo_angles[HAND_SERVO_COUNT];

/* USER CODE END PV */

void SystemClock_Config(void);
/* USER CODE BEGIN PFP */
static void Hand_ProcessSerial(void);
static void Hand_ProcessCommand(char *line);
static void Hand_Send(const char *text);
static void Hand_SendState(void);
static uint8_t Hand_GetAngleMax(uint8_t channel);

/* USER CODE END PFP */

/* USER CODE BEGIN 0 */
static void Hand_Send(const char *text)
{
  SerialPort_Write((const uint8_t *)text, (uint16_t)strlen(text));
}

static uint8_t Hand_GetAngleMax(uint8_t channel)
{
  if ((channel == HAND_THUMB_ROTATION_CHANNEL) ||
      (channel == HAND_THUMB_DISTAL_CHANNEL))
  {
    return HAND_THUMB_ANGLE_MAX;
  }
  return HAND_ANGLE_MAX;
}

static char *Hand_AppendAngle(char *dst, uint8_t angle)
{
  if (angle >= 100U)
  {
    *dst++ = (char)('0' + (angle / 100U));
  }
  if (angle >= 10U)
  {
    *dst++ = (char)('0' + ((angle / 10U) % 10U));
  }
  *dst++ = (char)('0' + (angle % 10U));
  return dst;
}

static void Hand_SendState(void)
{
  char response[64];
  char *cursor = response;
  uint8_t channel;

  memcpy(cursor, "STATE ", 6U);
  cursor += 6U;
  for (channel = 0U; channel < HAND_SERVO_COUNT; ++channel)
  {
    cursor = Hand_AppendAngle(cursor, servo_angles[channel]);
    *cursor++ = (channel == (HAND_SERVO_COUNT - 1U)) ? '\r' : ',';
  }
  *cursor++ = '\n';
  SerialPort_Write((uint8_t *)response, (uint16_t)(cursor - response));
}

static uint8_t Hand_ParseNumber(const char *text, uint32_t *value)
{
  char *end;

  if ((text == NULL) || (*text == '\0'))
  {
    return 0U;
  }
  *value = strtoul(text, &end, 10);
  return (*end == '\0') ? 1U : 0U;
}

static void Hand_ProcessCommand(char *line)
{
  char *command = strtok(line, " ");
  char *first = strtok(NULL, " ");
  char *second = strtok(NULL, " ");
  char *extra = strtok(NULL, " ");
  uint32_t channel;
  uint32_t angle;
  uint8_t i;

  if (command == NULL)
  {
    return;
  }

  if ((strcmp(command, "PING") == 0) && (first == NULL))
  {
    Hand_Send("PONG\r\n");
  }
  else if ((strcmp(command, "GET") == 0) && (first == NULL))
  {
    Hand_SendState();
  }
  else if ((strcmp(command, "SET") == 0) && (extra == NULL) &&
           Hand_ParseNumber(first, &channel) && Hand_ParseNumber(second, &angle))
  {
    if (channel >= HAND_SERVO_COUNT)
    {
      Hand_Send("ERR CHANNEL 0-10\r\n");
    }
    else if ((angle < HAND_ANGLE_MIN) ||
             (angle > Hand_GetAngleMax((uint8_t)channel)))
    {
      if (Hand_GetAngleMax((uint8_t)channel) == HAND_THUMB_ANGLE_MAX)
      {
        Hand_Send("ERR ANGLE 5-140\r\n");
      }
      else
      {
        Hand_Send("ERR ANGLE 5-170\r\n");
      }
    }
    else if (PCA9685_SetAngle(&hi2c1, (uint8_t)channel,
                              (uint8_t)angle) != HAL_OK)
    {
      Hand_Send("ERR I2C\r\n");
    }
    else
    {
      servo_angles[channel] = (uint8_t)angle;
      Hand_Send("OK\r\n");
    }
  }
  else if ((strcmp(command, "ALL") == 0) && (second == NULL) &&
           Hand_ParseNumber(first, &angle))
  {
    if ((angle < HAND_ANGLE_MIN) || (angle > HAND_ANGLE_MAX))
    {
      Hand_Send("ERR ANGLE 5-170\r\n");
      return;
    }
    for (i = 0U; i < HAND_SERVO_COUNT; ++i)
    {
      uint8_t channel_angle = (uint8_t)angle;
      uint8_t channel_max = Hand_GetAngleMax(i);

      if (channel_angle > channel_max)
      {
        channel_angle = channel_max;
      }
      if (PCA9685_SetAngle(&hi2c1, i, channel_angle) != HAL_OK)
      {
        Hand_Send("ERR I2C\r\n");
        return;
      }
      servo_angles[i] = channel_angle;
    }
    Hand_Send("OK\r\n");
  }
  else
  {
    Hand_Send("ERR COMMAND\r\n");
  }
}

static void Hand_ProcessSerial(void)
{
  static char line[RX_LINE_SIZE];
  static uint8_t length = 0U;
  uint8_t byte;

  if (!SerialPort_ReadByte(&byte, 5U))
  {
    return;
  }

  if ((byte == '\r') || (byte == '\n'))
  {
    if (length > 0U)
    {
      line[length] = '\0';
      Hand_ProcessCommand(line);
      length = 0U;
    }
  }
  else if (length < (RX_LINE_SIZE - 1U))
  {
    line[length++] = (char)byte;
  }
  else
  {
    length = 0U;
    Hand_Send("ERR LINE TOO LONG\r\n");
  }
}

/* USER CODE END 0 */

/**
  * @brief  The application entry point.
  * @retval int
  */
int main(void)
{

  /* MCU Configuration--------------------------------------------------------*/

  /* Reset of all peripherals, Initializes the Flash interface and the Systick. */
  HAL_Init();

  /* Configure the system clock */
  SystemClock_Config();

  /* Initialize all configured peripherals */
  MX_GPIO_Init();
  MX_I2C1_Init();
  /* USER CODE BEGIN 2 */
  uint8_t channel;

  SerialPort_Init();
  HAL_Delay(100U);
  if (PCA9685_Init(&hi2c1) != HAL_OK)
  {
    Error_Handler();
  }
  for (channel = 0U; channel < HAND_SERVO_COUNT; ++channel)
  {
    servo_angles[channel] = HAND_ANGLE_MIN;
    if (PCA9685_SetAngle(&hi2c1, channel, HAND_ANGLE_MIN) != HAL_OK)
    {
      Error_Handler();
    }
  }
  Hand_Send("READY HAND11 5-170 THUMB-ROT-DIST 5-140\r\n");

  /* USER CODE END 2 */

  /* Infinite loop */
  /* USER CODE BEGIN WHILE */
  while (1)
  {
    /* USER CODE END WHILE */

    /* USER CODE BEGIN 3 */
    Hand_ProcessSerial();
  }
  /* USER CODE END 3 */
}

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


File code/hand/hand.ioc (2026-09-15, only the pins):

Mcu.UserName=STM32F103C8Tx
PA13.Signal=SYS_JTMS-SWDIO
PA14.Signal=SYS_JTCK-SWCLK
PA9.Signal=USART1_TX
PA10.Signal=USART1_RX
PB6.Signal=I2C1_SCL
PB7.Signal=I2C1_SDA
PC14-OSC32_IN.Signal=RCC_OSC32_IN
PC15-OSC32_OUT.Signal=RCC_OSC32_OUT
PD0-OSC_IN.Signal=RCC_OSC_IN
PD1-OSC_OUT.Signal=RCC_OSC_OUT

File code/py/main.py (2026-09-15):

"""使用 RGB-D 手部关键点连续控制 11 自由度机械手。

处理流程：采集彩色图和对齐深度图，检测右手关键点，将关键点反投影为
真实 3D 坐标，计算关节角并经过滤波、限速后通过串口发送给控制板。
"""

from __future__ import annotations

import argparse
import sys
import time
from collections import deque
from pathlib import Path

import cv2
import mediapipe as mp
import numpy as np
from mediapipe.tasks import python
from mediapipe.tasks.python import vision

from rgbd_hand_3d import (
    BoneLengthConstraint,
    OrbbecCamera,
    PointSmoother,
    calculate_angle,
    landmark_pixels,
    reconstruct_points,
)

try:
    import serial
    from serial.tools import list_ports
except ImportError:
    serial = None
    list_ports = None


BASE_DIR = Path(__file__).resolve().parent
HAND_MODEL = BASE_DIR / "hand_landmarker.task"
SERIAL_PORT = "COM20"
BAUD_RATE = 115200

# 固件侧的机械限位；通道顺序必须与控制板和机械接线保持一致。
SERVO_MIN = 5
SERVO_MAXES = (140, 170, 140, 170, 170, 170, 170, 170, 170, 170, 170)
SERVO_NAMES = (
    "thumb rotation",
    "thumb proximal",
    "thumb distal",
    "index proximal",
    "index distal",
    "middle proximal",
    "middle distal",
    "ring proximal",
    "ring distal",
    "pinky proximal",
    "pinky distal",
)

# 每个通道的实测范围：(弯曲角, 伸展角)。
# 请用 --calibrate 采集后替换。方向由标定自动判定，这里保持"弯曲 < 伸展"。
MP_RANGES = (
    (  30.0,   47.2),  # CH00 thumb rotation  SWAPPED
    ( 136.1,  162.8),  # CH01 thumb proximal  OK
    ( 100.8,  162.5),  # CH02 thumb distal  OK
    ( 105.5,  167.7),  # CH03 index proximal  OK
    (  98.3,  168.9),  # CH04 index distal  OK
    (  81.3,  165.5),  # CH05 middle proximal  OK
    (  90.0,  160.5),  # CH06 middle distal  OK
    (  77.9,  164.4),  # CH07 ring proximal  OK
    ( 103.4,  161.1),  # CH08 ring distal  OK
    (  86.5,  170.3),  # CH09 pinky proximal  OK
    ( 107.8,  157.6),  # CH10 pinky distal  OK
)

# 如果某个通道标定后发现方向反了，用这个集合翻转。
INVERT_CHANNELS: set[int] = set()

FINGER_JOINTS = (
    (5, 6, 7, 8),
    (9, 10, 11, 12),
    (13, 14, 15, 16),
    (17, 18, 19, 20),
)
HAND_CONNECTIONS = (
    (0, 1), (1, 2), (2, 3), (3, 4),
    (0, 5), (5, 6), (6, 7), (7, 8),
    (5, 9), (9, 10), (10, 11), (11, 12),
    (9, 13), (13, 14), (14, 15), (15, 16),
    (13, 17), (17, 18), (18, 19), (19, 20), (0, 17),
)

SMOOTHING_ALPHA = 0.35
MAX_STEP_PER_FRAME = 8.0
SEND_INTERVAL = 0.05
RECONNECT_INTERVAL = 2.0
STABLE_FRAMES_REQUIRED = 3
MEDIAN_WINDOW = 5          # 中值滤波窗口
MIN_VALID_DEPTH_LANDMARKS = 16


def clamp(value: float, lower: float, upper: float) -> float:
    """把数值限制在闭区间 [lower, upper]。"""
    return max(lower, min(upper, value))


def extract_joint_angles(points: np.ndarray) -> list[float]:
    """从深度相机反投影得到的米制 3D 关键点提取 11 个关节角。"""
    angles = [calculate_angle(points[5], points[0], points[2])]
    angles.append(calculate_angle(points[1], points[2], points[3]))
    angles.append(calculate_angle(points[2], points[3], points[4]))
    for mcp, pip, dip, tip in FINGER_JOINTS:
        angles.append(calculate_angle(points[mcp], points[pip], points[dip]))
        angles.append(calculate_angle(points[pip], points[dip], points[tip]))
    return angles


def joint_angles_to_servo(joint_angles: list[float]) -> list[float]:
    """按标定范围把人体关节角线性映射为各通道舵机角度。"""
    servo_angles = []
    for channel, (joint_angle, (mp_min, mp_max)) in enumerate(zip(joint_angles, MP_RANGES)):
        span = mp_max - mp_min
        if abs(span) < 1e-6:
            ratio = 0.0
        else:
            ratio = clamp((joint_angle - mp_min) / span, 0.0, 1.0)
        if channel in INVERT_CHANNELS:
            ratio = 1.0 - ratio
        value = SERVO_MIN + ratio * (SERVO_MAXES[channel] - SERVO_MIN)
        servo_angles.append(clamp(value, SERVO_MIN, SERVO_MAXES[channel]))
    return servo_angles


class AngleFilter:
    """中值滤波去尖峰 + 一阶低通平滑。"""

    def __init__(self, channels: int):
        self.median_buffers = [deque(maxlen=MEDIAN_WINDOW) for _ in range(channels)]
        self.filtered: list[float] | None = None

    def update(self, raw: list[float]) -> list[float]:
        medians = []
        for channel, value in enumerate(raw):
            buf = self.median_buffers[channel]
            buf.append(value)
            medians.append(float(np.median(buf)))
        if self.filtered is None:
            self.filtered = medians[:]
        else:
            self.filtered = [
                old + SMOOTHING_ALPHA * (med - old)
                for old, med in zip(self.filtered, medians)
            ]
        return self.filtered[:]

    def reset(self) -> None:
        for buffer in self.median_buffers:
            buffer.clear()
        self.filtered = None


class ServoTracker:
    """让舵机角度以每帧最大步长逼近目标。"""

    def __init__(self, channels: int):
        self.current = [float(SERVO_MIN)] * channels

    def step(self, target: list[float]) -> list[float]:
        result = []
        for channel, (old, new) in enumerate(zip(self.current, target)):
            delta = clamp(new - old, -MAX_STEP_PER_FRAME, MAX_STEP_PER_FRAME)
            result.append(clamp(old + delta, SERVO_MIN, SERVO_MAXES[channel]))
        self.current = result
        return result
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

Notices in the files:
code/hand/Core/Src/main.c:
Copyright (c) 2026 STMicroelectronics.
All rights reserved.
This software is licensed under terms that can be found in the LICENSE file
